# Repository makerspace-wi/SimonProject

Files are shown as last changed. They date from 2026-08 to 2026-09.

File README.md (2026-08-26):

# Simon Project

ESP32-basierte Steuerung fuer Fallblattanzeigen (MAN/Krone/Vossloh) mit:
- WiFi Access Point
- Weboberflaeche/HTTP-API
- Serieller Ausgabe im Krone-Protokoll
- I2C-Transfer von Byte-Werten an 3 Slave-Adressen (ADTrans)

## Projektziel

Dieses Projekt stellt mit einem ESP32 einen lokalen Access Point bereit. Ueber HTTP-Endpoints koennen Anzeigeinhalte gesetzt oder geloescht werden. Die Ausgabe an die Fallblattmodule erfolgt seriell im Format:

- Startbyte: `0x88`
- Adresse: `adress`
- Wert: `flip`
- Endbyte: `0x81`

## Verwendete Plattform

- MCU/Board: ESP32 (`wemos_d1_uno32`)
- Framework: Arduino
- Build-System: PlatformIO
- Webserver: `ESP32WebServer`
- mDNS: `ESPmDNS`
- I2C: `Wire`

Konfiguration: [platformio.ini](platformio.ini)

## Build und Upload

### Build

```bash
~/.platformio/penv/bin/platformio run
```

### Upload (Beispiel)

```bash
~/.platformio/penv/bin/platformio run -t upload
```

## Netzwerkverhalten

Beim Start erzeugt der ESP32 einen Access Point:
- SSID: `fallblatt.local`
- Passwort: `Fallblattanzeige`

Zusatz: mDNS wird mit Hostname `fallblatt` initialisiert.

## HTTP-Endpoints

Implementierung in [src/main.cpp](src/main.cpp).

### 1) Startseite

- `GET /`
- Liefert die HTML-Oberflaeche aus `MAIN_page` (Datei [src/web.h](src/web.h)).

### 2) Anzeige loeschen

- `GET /clear`
- Loescht/neutralisiert alle angesteuerten Fallblattpositionen.

### 3) Anzeige setzen

- `GET /flip`
- Erwartete Query-Parameter:
  - `b` = Betreiber
  - `g` = Gattung
  - `n` = Zugnummer
  - `s` = Abfahrtsstunde
  - `m` = Abfahrtsminute
  - `i1` = Info 1
  - `i2` = Info 2
  - `d` = Zwischenziel
  - `z` = Ziel

Beispiel:

```text
/flip?b=1&g=2&n=42&s=12&m=34&i1=5&i2=6&d=7&z=8
```

Hinweis:
- Der Endpoint `/flip` steuert zusaetzlich 3 I2C-Module (ADTrans) ueber `I2C_ADDR_1..3`.
- Je nach Laenge der Zugnummer werden Ziffern auf UART-Fallblattmodule und I2C-Module verteilt.

### 4) Zweites Modul (direkt im Programm gesteuert)

Die zweite serielle Schnittstelle (19200 Baud, BREAK-Protokoll) wird ohne eigenen HTTP-Endpoint direkt im Programmablauf gesteuert.

Aktuell erfolgt die Ansteuerung am Ende von `/flip` mit:

- Zieladresse aus `MODULE2_DIRECT_ADDR`
- Position aus dem bereits berechneten Feld `ziel`

Damit geht die Kommunikation fuer das zweite Modul nicht separat ueber den Webserver.

## I2C-Konfiguration

Standardwerte in [platformio.ini](platformio.ini):

- `I2C_ADDR_1=0x38`
- `I2C_ADDR_2=0x39`
- `I2C_ADDR_3=0x3A`

Optionale Pinbelegung (auskommentiert):
- `I2C_SDA_PIN`
- `I2C_SCL_PIN`

Wenn beide Pins gesetzt sind, wird `Wire.begin(SDA, SCL)` verwendet.
Andernfalls nutzt das Projekt `Wire.begin()` mit Board-Default.

## Genutzte IO-Pins

Aktueller Stand gemaess [platformio.ini](platformio.ini) und [src/main.cpp](src/main.cpp):

- Debug-UART (`Serial`): ueber USB-Seriell (Monitor 115200 Baud).
- Signal-UART (`Serial2`, 4800 Baud, 8E2):
  - TX: GPIO17 (`UART_SIGNAL_TX_PIN`)
  - RX: GPIO16 (`UART_SIGNAL_RX_PIN`)
- Modul-2-UART (`Serial1`, 19200 Baud, 8N1, BREAK-faehig):
  - TX: GPIO26 (`UART_MODULE2_TX_PIN`)
  - RX: GPIO27 (`UART_MODULE2_RX_PIN`)
  - Optional RS485 Driver-Enable: `UART_MODULE2_RS485_DE_PIN` (Standard `-1` = aus)
- I2C (`Wire`):
  - Aktuell keine festen Pins im Build-Flag gesetzt.
  - Es werden daher die Board-Defaults verwendet (`Wire.begin()`).
  - Optional konfigurierbar ueber `I2C_SDA_PIN` und `I2C_SCL_PIN` in [platformio.ini](platformio.ini).

Hinweis:
- Auf vielen ESP32-Boards liegt USB-Debug intern auf UART0 (typisch TX0=GPIO1, RX0=GPIO3).
- Fuer die Fallblattansteuerung wird ausschliesslich `Serial2` genutzt.
- Die ADTrans-I2C-Module werden mit `sendByte(...)` angesteuert (kein separater HTTP-I2C-Endpoint).

## Fallblatt-Adressen (seriell)

Die adressierten Module sind in [src/main.cpp](src/main.cpp) festgelegt, u. a.:
- Logo: `0x05`
- Gattung: `0x04`
- Zeichen 1/2: `0x03`, `0x02`
- Stunde/Minute: `0x01`, `0x00`
- Info 1/2: `0x07`, `0x06`
- Zwischenziel/Ziel: `0x08`, `0x09`

## Troubleshooting

### Build-Task in VS Code schlaegt fehl, Terminal-Build funktioniert

Symptom:
- VS-Code-Task meldet Fehler, manueller Build ist erfolgreich.

Pruefung/Fix:
- Sicherstellen, dass [/.vscode/tasks.json](.vscode/tasks.json) den PlatformIO-Pfad aus dem Python-Environment nutzt.
- Build direkt testen:

```bash
~/.platformio/penv/bin/platformio run
```

### Include-Fehler / IntelliSense findet Header nicht

Symptom:
- Meldung wie "Aktualisieren Sie Ihren includePath".

Pruefung/Fix:
- Einmal erfolgreichen Build ausfuehren, damit PlatformIO die Projektmetadaten aktualisiert.
- VS Code neu laden, falls die Meldung bestehen bleibt.
- In [platformio.ini](platformio.ini) das richtige Environment pruefen (`ESP32_WROOM`).

### Upload funktioniert nicht

Symptom:
- `run -t upload` bricht mit Port- oder Verbindungsfehler ab.

Pruefung/Fix:
- USB-Kabel/Port wechseln.
- Board-Typ in [platformio.ini](platformio.ini) pruefen (`wemos_d1_uno32`).
- Upload separat testen:

```bash
~/.platformio/penv/bin/platformio run -t upload
```

### I2C-Geraet reagiert nicht

Symptom:
- Ziffern auf den ADTrans-Modulen fehlen oder bleiben auf Leerwert.

Pruefung/Fix:
- I2C-Adressen in [platformio.ini](platformio.ini) mit den Slave-Adressen abgleichen (`I2C_ADDR_1..3`).
- Falls eigene Pins noetig sind, `I2C_SDA_PIN` und `I2C_SCL_PIN` in [platformio.ini](platformio.ini) aktivieren.
- GND zwischen ESP32 und I2C-Slaves gemeinsam verbinden.

### mDNS/Hostname nicht erreichbar

Symptom:
- `fallblatt.local` wird nicht aufgeloest.

Pruefung/Fix:
- Direkt per IP aufrufen statt Hostname.
- Sicherstellen, dass das Endgeraet im Access-Point des ESP32 eingebucht ist.
- AP-Daten pruefen: SSID `fallblatt.local`, Passwort `Fallblattanzeige`.

## Hinweise

- Das Projekt ist fuer die aktuelle ESP32-PlatformIO-Umgebung ausgelegt.
- Bei Problemen zuerst Build lokal pruefen und die Werte in [platformio.ini](platformio.ini) kontrollieren.

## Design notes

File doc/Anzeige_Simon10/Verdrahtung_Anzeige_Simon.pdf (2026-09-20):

Tabelle1

Anzeige Benennung Farbe
1
| GND | sw | 1
2
3
24V | or 4
5
6
7 | D5 | gn | 6
8 | D4 | or | 5
9 | D3 | ge | 4
10 | D2 | ws | 3
11 | D1 | rt | 2
12 | D0 | sw | 1
13 | REL | rt | 2
14 | ~24V | bl

### 15 bl

I2C
1 | GND | sw | 1
2 | 5V | rt | 2
3 | SDA | ge | 3
4 | SLC | ws | 4

RS485
1 | 5V | rt
2 | GND | sw

### 3 Data+ 4 Data-5 DI

6 | DE | }

### 7 RE 8 RO

Netzteil
1 ~230V L
2 ~230V N
1.1 | ~18V | bl
1.2 | ~18V | bl
2.1 | 27V | vio
2.2 | GND | sw
3.1 | 24V | or
3.2 | GND | sw

PCB
J1

PCB
J2

PCB
J3

PCB
RS485

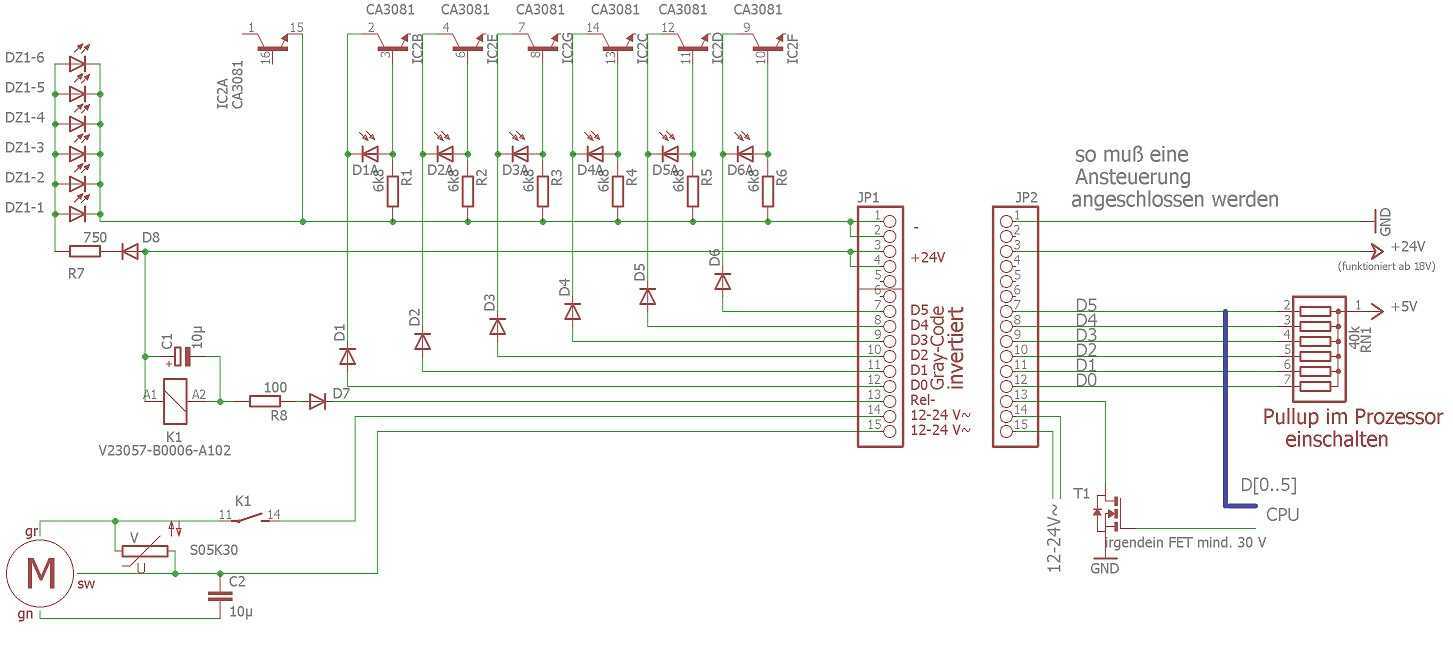
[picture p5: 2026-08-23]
doc/Anzeige_Simon10/ADTrans.jpeg

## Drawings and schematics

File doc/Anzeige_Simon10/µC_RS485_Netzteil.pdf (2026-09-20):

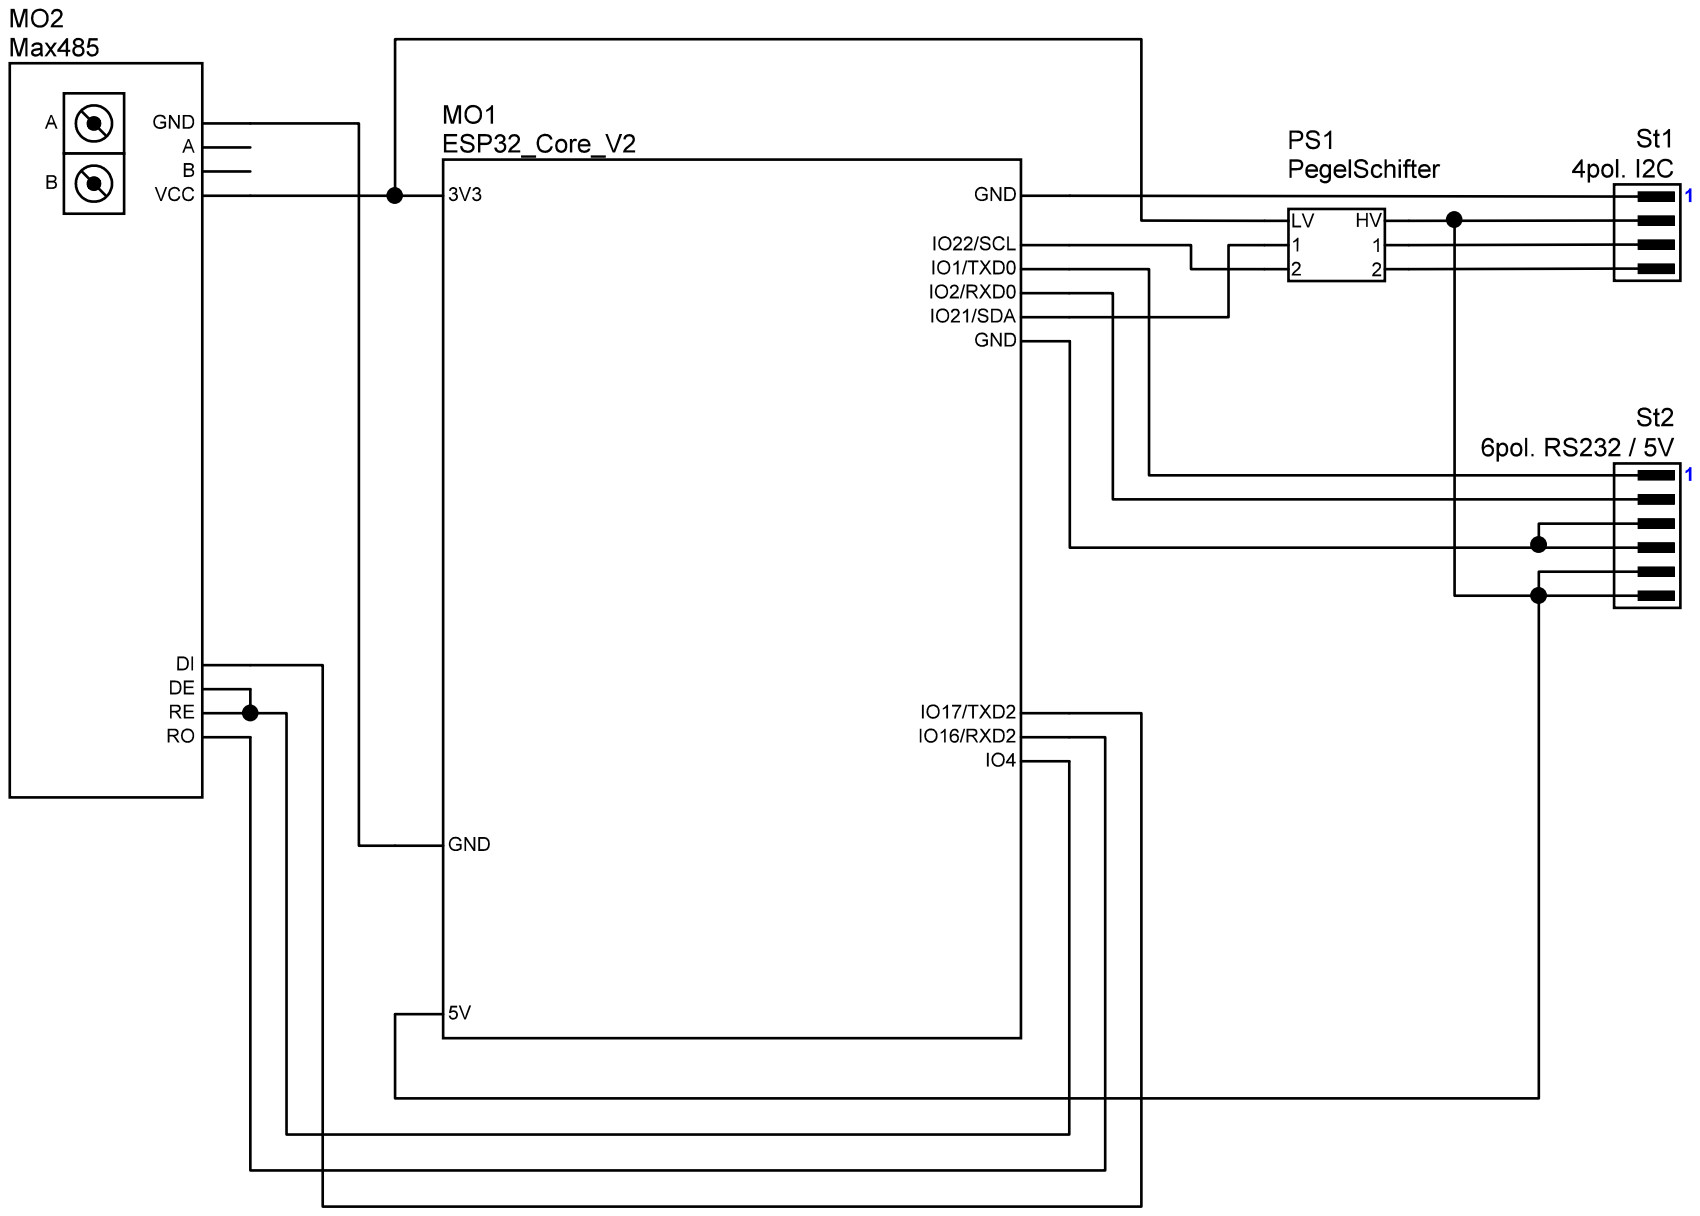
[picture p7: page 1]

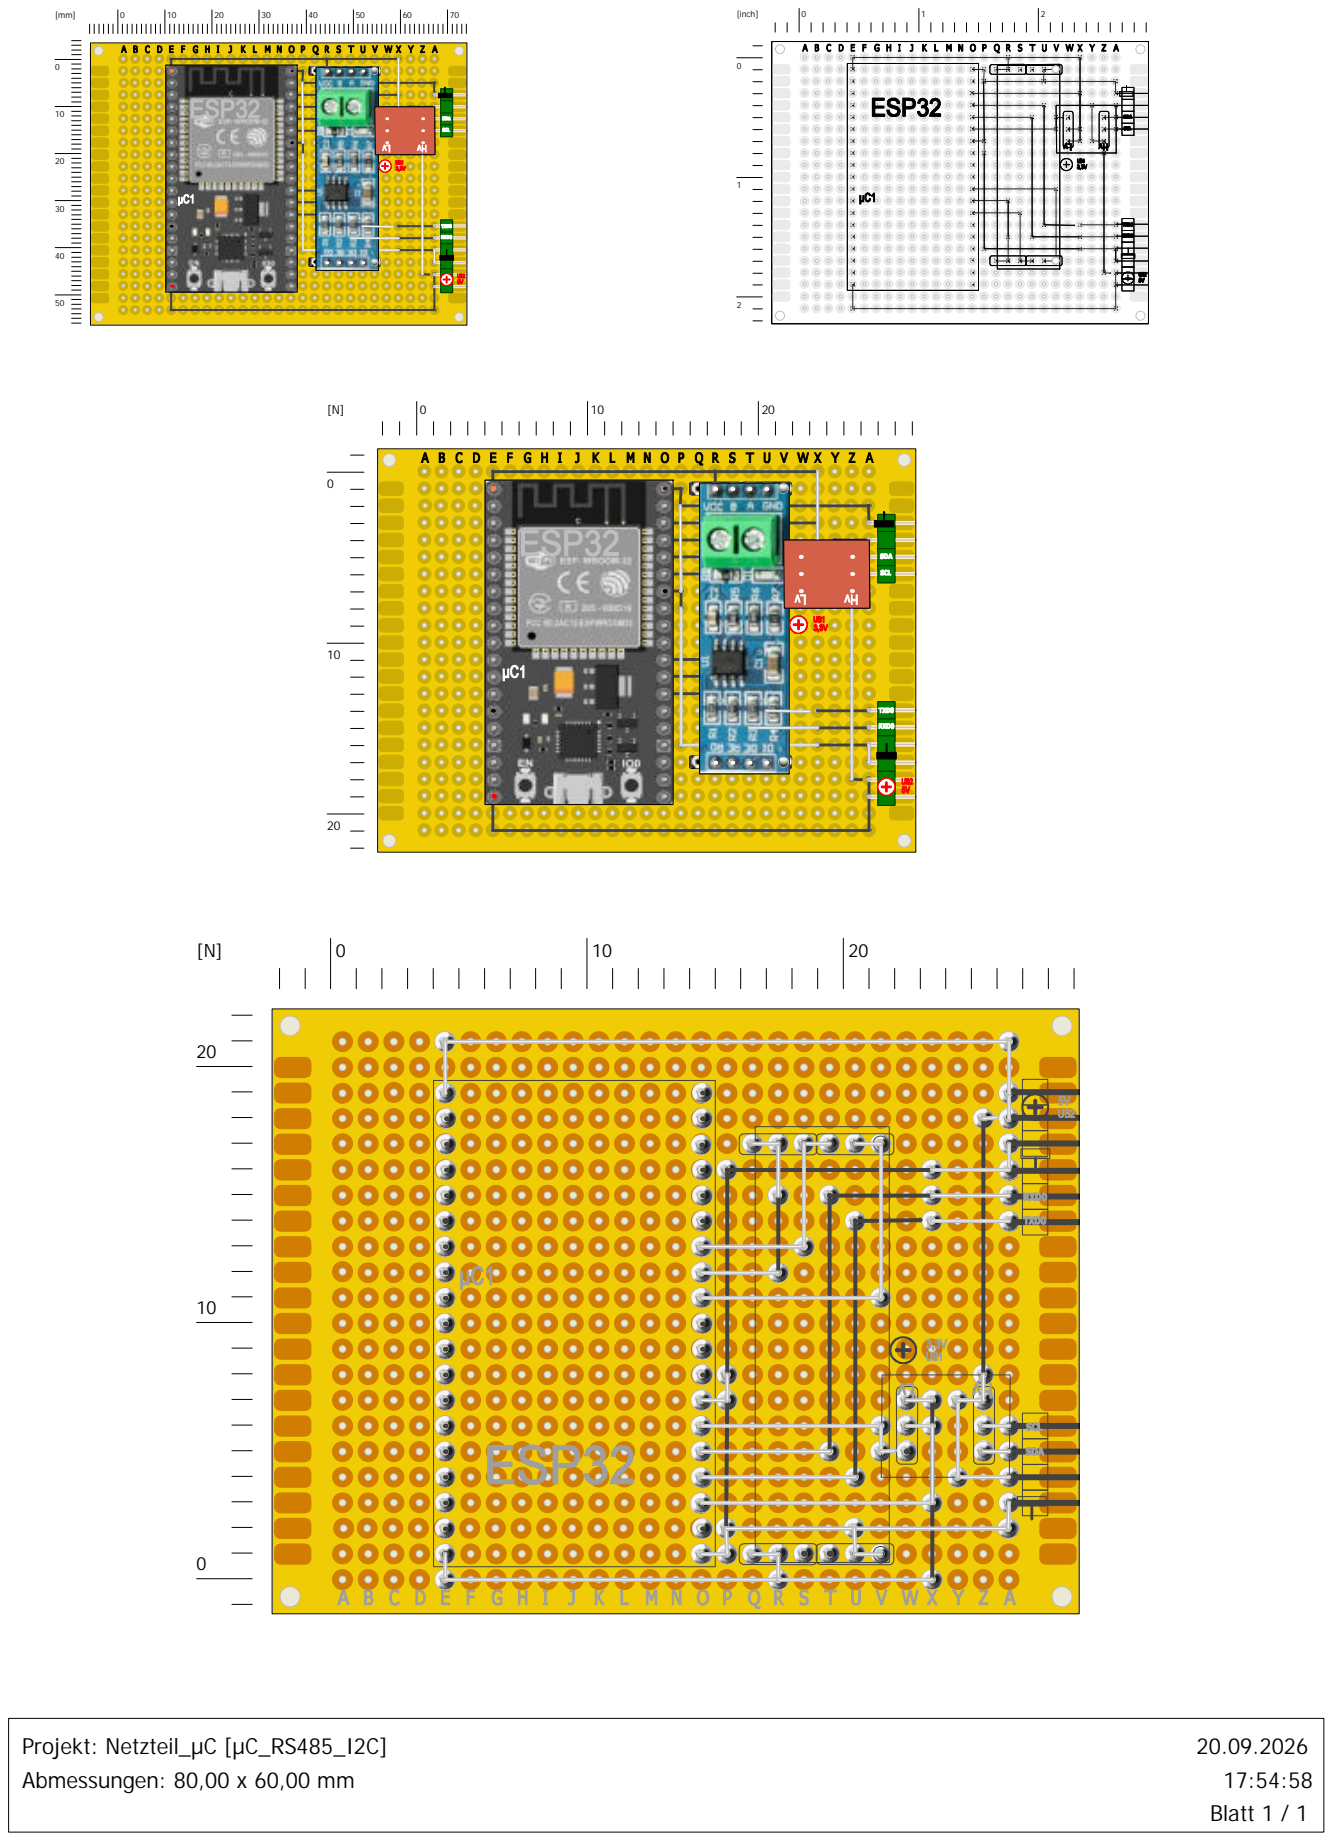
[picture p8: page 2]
[inch]; Projekt: Netzteil_µC [µC_RS485_I2C] Abmessungen: 80,00 x 60,00 mm; 20.09.2026 17:54:58 Blatt 1 / 1

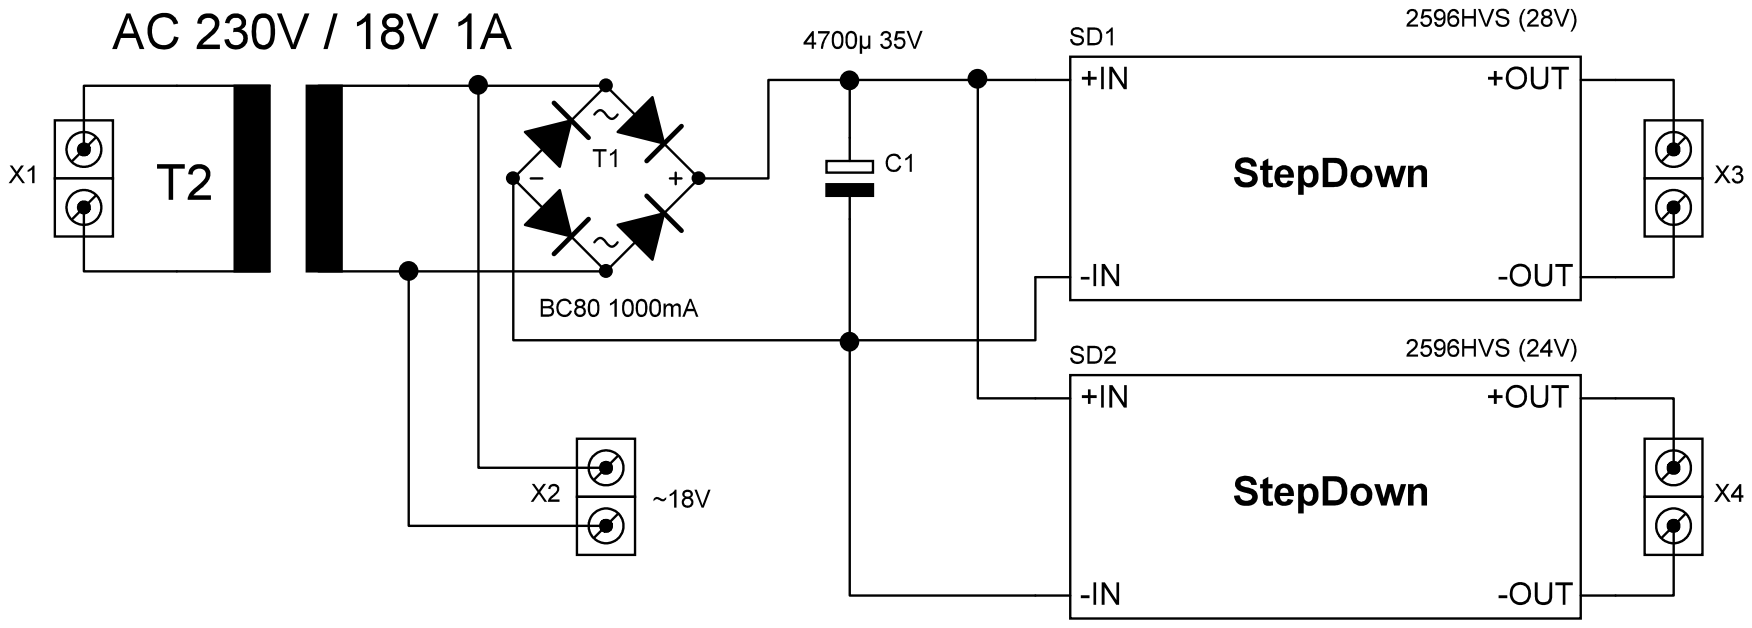
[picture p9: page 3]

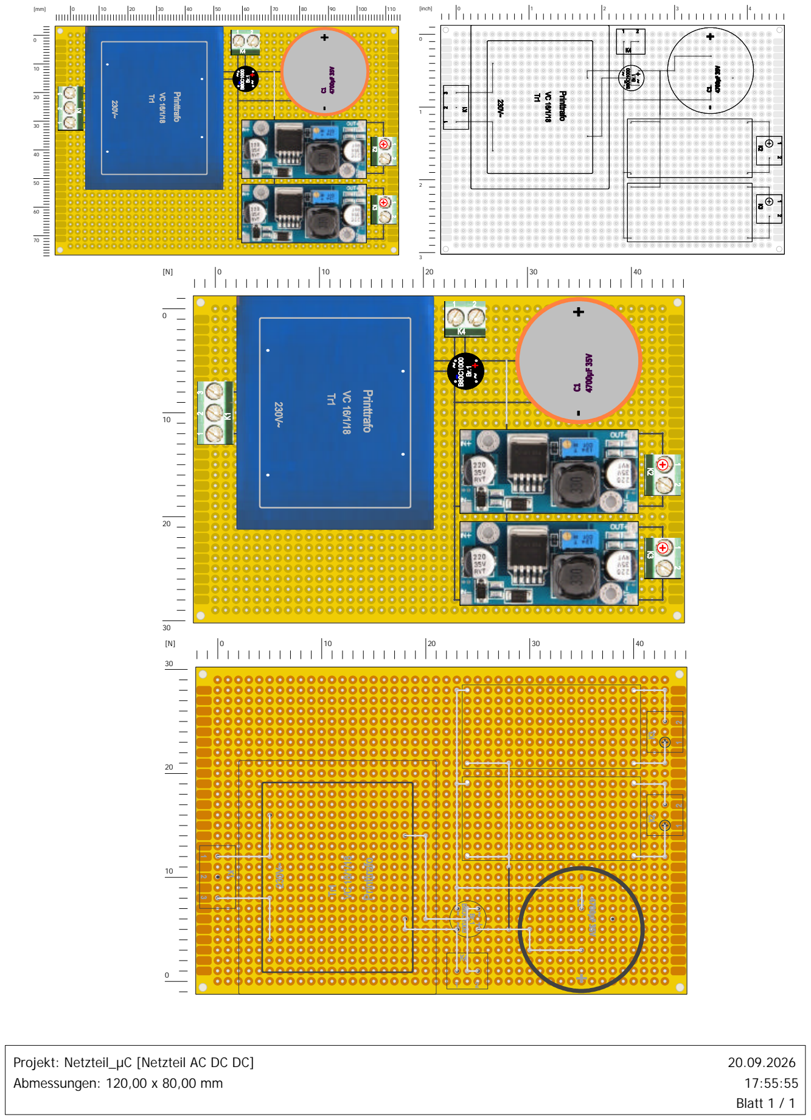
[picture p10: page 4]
[inch]; 20.09.2026 17:55:55 Blatt 1 / 1

Projekt: Netzteil_µC [Netzteil AC DC DC]
Abmessungen: 120,00 x 80,00 mm

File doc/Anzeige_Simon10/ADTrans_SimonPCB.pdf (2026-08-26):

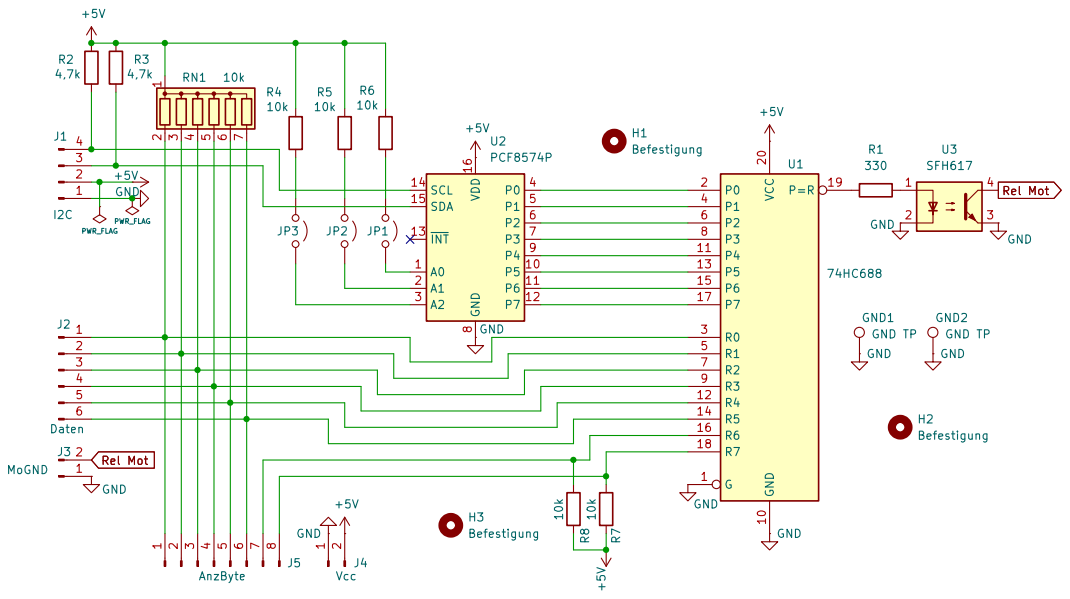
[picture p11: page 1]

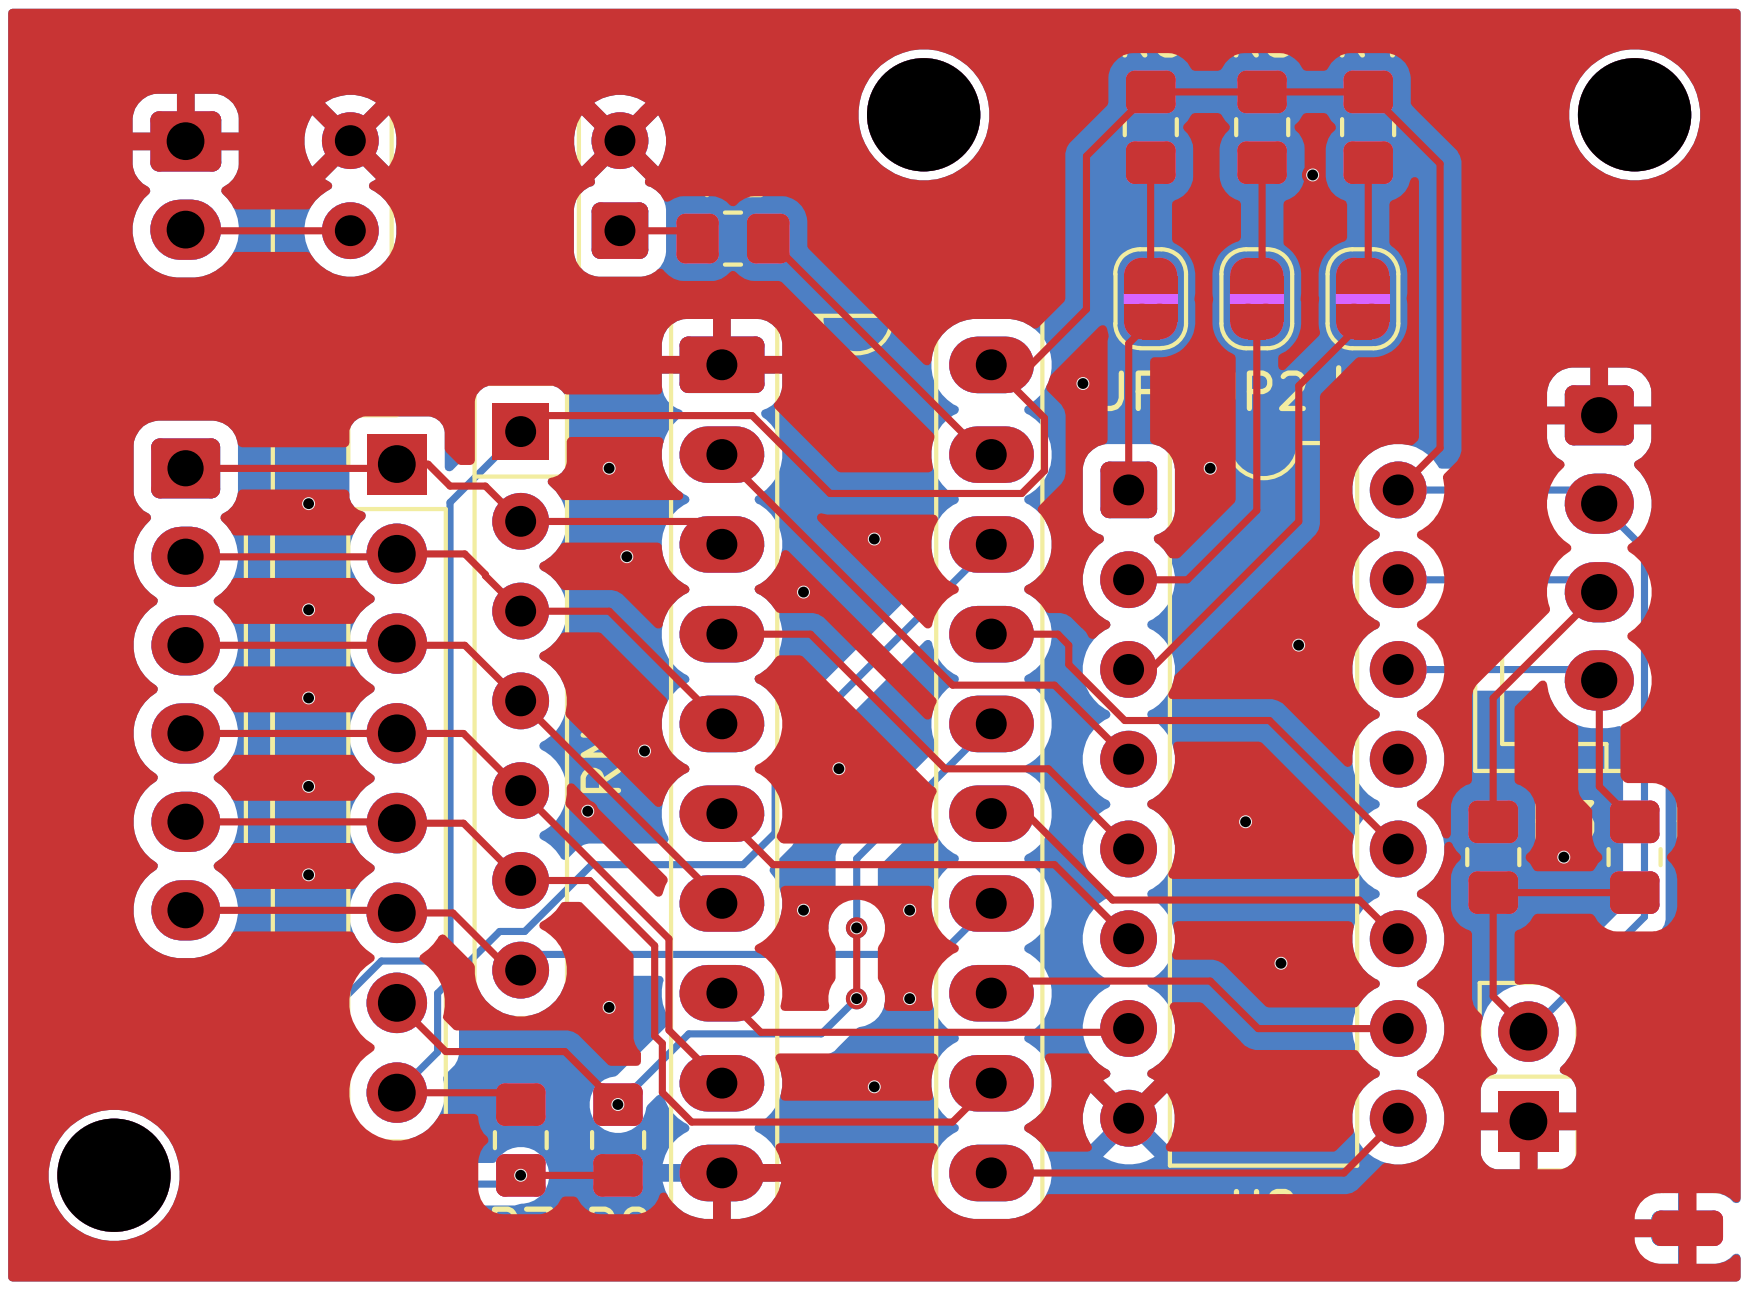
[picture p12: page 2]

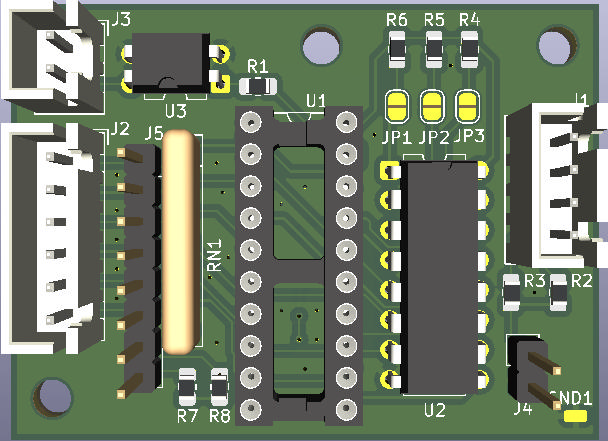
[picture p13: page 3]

1/1

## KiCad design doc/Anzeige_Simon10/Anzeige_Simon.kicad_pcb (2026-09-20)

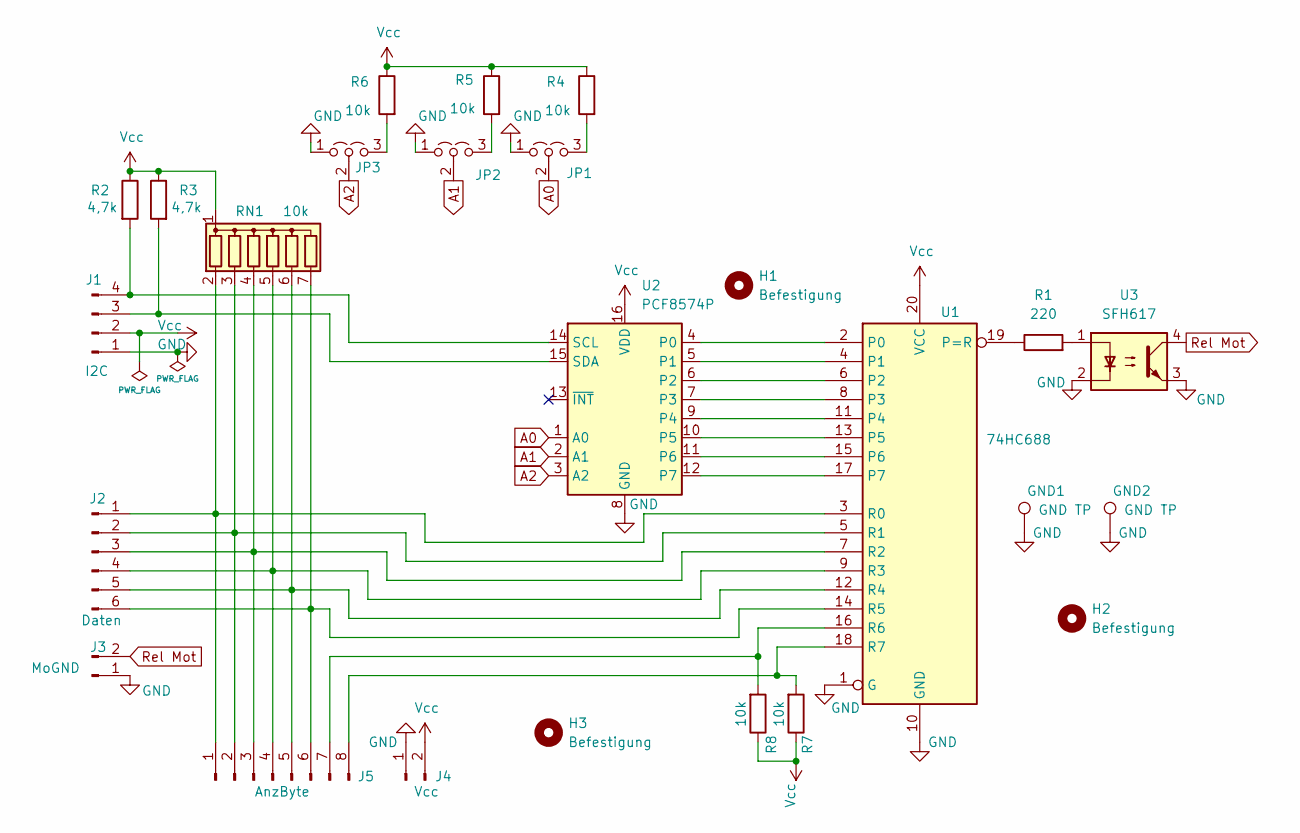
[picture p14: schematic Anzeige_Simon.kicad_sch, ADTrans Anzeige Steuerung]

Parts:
GND1, GND2: GND TP; SolderWirePad_1x01_SMD_1x2mm
H1, H2, H3: Befestigung; MountingHole_3.2mm_M3_ISO14580
J1: I2C; JST_XH_B4B-XH-A_1x04_P2.50mm_Vertical
J2: Daten; JST_XH_B6B-XH-A_1x06_P2.50mm_Vertical
J3: MoGND; JST_XH_B2B-XH-A_1x02_P2.50mm_Vertical
J4: Vcc; PinHeader_1x02_P2.54mm_Vertical
J5: AnzByte; PinHeader_1x08_P2.54mm_Vertical
JP1, JP2, JP3: Jumper_3_Open; SolderJumper-3_P1.3mm_Open_RoundedPad1.0x1.5mm
R1: 220; R_0805_2012Metric_Pad1.20x1.40mm_HandSolder
R2, R3: 4,7k; R_0805_2012Metric_Pad1.20x1.40mm_HandSolder
R4, R5, R6, R7, R8: 10k; R_0805_2012Metric_Pad1.20x1.40mm_HandSolder
RN1: 10k; R_Array_SIP7
U1: 74HC688; DIP-20_W7.62mm_Socket_LongPads
U2: PCF8574P; DIP-16_W7.62mm
U3: SFH617; DIP-4_W7.62mm

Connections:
A0: JP1.2 (C), U2.1 (A0)
A1: JP2.2 (C), U2.2 (A1)
A2: JP3.2 (C), U2.3 (A2)
GND: GND1.1 (1_1), GND2.1 (1_1), J1.1, J3.1, J4.1, JP1.1 (A), JP2.1 (A), JP3.1 (A), U1.1 (G), U1.10 (GND), U2.8 (GND), U3.2, U3.3
unnamed: J1.3, R3.2, U2.15 (SDA)
unnamed: J1.4, R2.2, U2.14 (SCL)
unnamed: J2.1, J5.1, RN1.2 (R1), U1.3 (R0)
unnamed: J2.2, J5.2, RN1.3 (R2), U1.5 (R1)
unnamed: J2.3, J5.3, RN1.4 (R3), U1.7 (R2)
unnamed: J2.4, J5.4, RN1.5 (R4), U1.9 (R3)
unnamed: J2.5, J5.5, RN1.6 (R5), U1.12 (R4)
unnamed: J2.6, J5.6, RN1.7 (R6), U1.14 (R5)
unnamed: J5.7, R8.2, U1.16 (R6)
unnamed: J5.8, R7.2, U1.18 (R7)
unnamed: JP1.3 (B), R4.2
unnamed: JP2.3 (B), R5.2
unnamed: JP3.3 (B), R6.2
unnamed: R1.2, U3.1
unnamed: U1.2 (P0), U2.4 (P0)
unnamed: U1.4 (P1), U2.5 (P1)
unnamed: U1.6 (P2), U2.6 (P2)
unnamed: U1.8 (P3), U2.7 (P3)
unnamed: U1.11 (P4), U2.9 (P4)
unnamed: U1.13 (P5), U2.10 (P5)
unnamed: U1.15 (P6), U2.11 (P6)
unnamed: U1.17 (P7), U2.12 (P7)
unnamed: R1.1, U1.19 (P=R)
Rel Mot: J3.2, U3.4
Vcc: J1.2, J4.2, R2.1, R3.1, R4.1, R5.1, R6.1, R7.1, R8.1, RN1.1 (common), U1.20 (VCC), U2.16 (VDD)

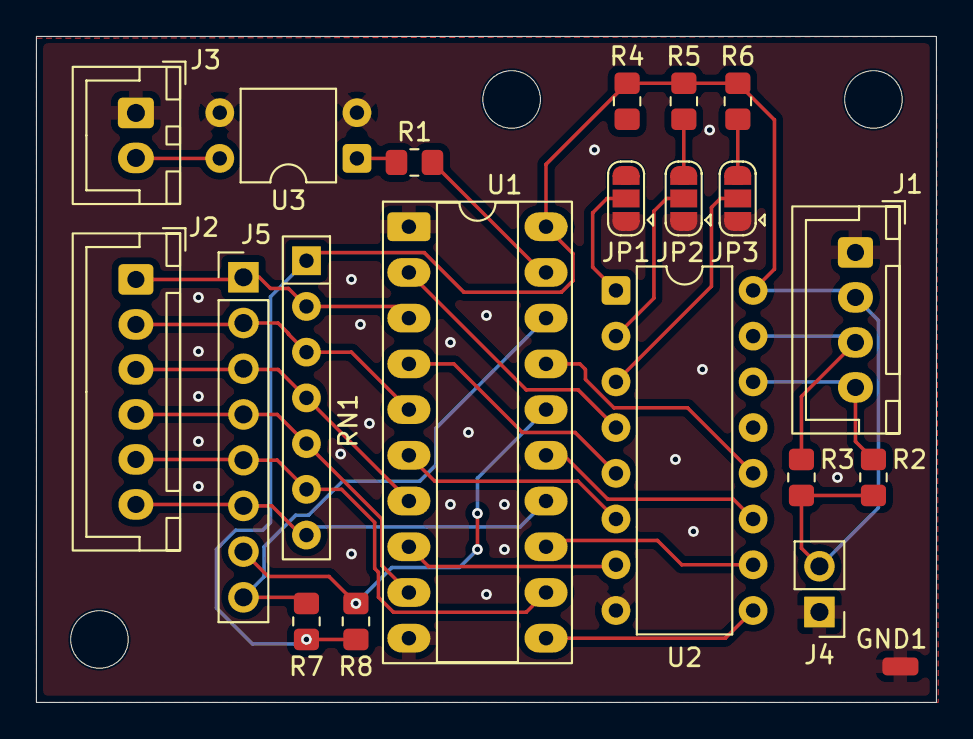
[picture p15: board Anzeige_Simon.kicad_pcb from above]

Board: 2 copper layers, 50.0 x 37.0 mm, 25 parts (1 on the bottom side), 29 nets.

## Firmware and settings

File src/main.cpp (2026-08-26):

#include <Arduino.h>
#include <Wire.h>
// Alex Kohl 2024 Krone Fallblattansteuerung mit ESP32 Email an mich: alex@alex14.de
// ESP32 als Wifi-AP zur Ansteuerung von MAN/Krone/Vossloh Fallblattanzeigen
// Module sind ueber eine serielle Verbindung angebunden
// Aufbau Message: [88] [Adresse] [Blatt] [81]
//  ZUM PROGRAMMIEREN: ESP32 UMBEDINGT von Adapter AUSSTECKEN!

// Einstellungen zum Programmieren:
// 1. PlatformIO-Umgebung: ESP32_WROOM
// 2. Board: wemos_d1_uno32
// 3. Framework: arduino
// >>>> Wenn unten orange Fehlermeldungen kommen, stimmt etwas nicht.
//      Meistens hilft Google oder mich einfach fragen.

// Sonderzeichen zu "Ersatzzeichen": https://www-user.tu-chemnitz.de/~lfe/selfhtml61/tcad.htm

// https://github.com/espressif/arduino-esp32/tree/master/libraries/WebServer
#include <ESP32WebServer.h>
const char *WiFiName = "fallblatt.local";
const char *WiFiPass = "Fallblattanzeige";
// https://github.com/espressif/arduino-esp32/tree/master/libraries/ESPmDNS
#include <ESPmDNS.h>

// web.h: ausgelagertes Webdokument, enthaelt das gesamte HTML
#include "web.h"

int address = 0;
int verschubzahl = 0;
ESP32WebServer server(80);

int laststatus = 3;

void returnConfigPage();
void clear();
void flip();
void setflip(byte adress, byte flip);
void sendByte(byte i2cAddress, byte zahl);
byte bin2grayi(byte n);

void module2SendCommand(uint8_t command, uint8_t address, const uint8_t *payload, size_t payloadLen);
void module2SetPosition(uint8_t address, uint8_t position);
void updateModule2Direct();

#ifndef UART_DEBUG_BAUD
#define UART_DEBUG_BAUD 115200
#endif

#ifndef UART_SIGNAL_BAUD
#define UART_SIGNAL_BAUD 4800
#endif

#ifndef UART_SIGNAL_RX_PIN
#define UART_SIGNAL_RX_PIN 16
#endif

#ifndef UART_SIGNAL_TX_PIN
#define UART_SIGNAL_TX_PIN 17
#endif

#ifndef UART_MODULE2_BAUD
#define UART_MODULE2_BAUD 19200
#endif

#ifndef UART_MODULE2_RX_PIN
#define UART_MODULE2_RX_PIN 27
#endif

#ifndef UART_MODULE2_TX_PIN
#define UART_MODULE2_TX_PIN 26
#endif

#ifndef UART_MODULE2_BREAK_BITS
#define UART_MODULE2_BREAK_BITS 24
#endif

#ifndef UART_MODULE2_RS485_DE_PIN
#define UART_MODULE2_RS485_DE_PIN -1
#endif

#ifndef MODULE2_DIRECT_ENABLED
#define MODULE2_DIRECT_ENABLED 1
#endif

#ifndef MODULE2_DIRECT_ADDR
#define MODULE2_DIRECT_ADDR 0x0A
#endif

#ifndef I2C_ADDR_1
#define I2C_ADDR_1 0x10
#endif

#ifndef I2C_ADDR_2
#define I2C_ADDR_2 0x11
#endif

#ifndef I2C_ADDR_3
#define I2C_ADDR_3 0x12
#endif

#ifndef I2C_SDA_PIN
#define I2C_SDA_PIN -1
#endif

#ifndef I2C_SCL_PIN
#define I2C_SCL_PIN -1
#endif

// I2C-Zieladressen fuer Integer-Transfers
const uint8_t i2cAddress1 = static_cast<uint8_t>(I2C_ADDR_1);
const uint8_t i2cAddress2 = static_cast<uint8_t>(I2C_ADDR_2);
const uint8_t i2cAddress3 = static_cast<uint8_t>(I2C_ADDR_3);

// Adressen der Fallblattmodule
byte logoadress = 0x05;
byte gattungadress = 0x04;
byte char1 = 0x03;
byte char2 = 0x02;

byte stdadress = 0x01;
byte minadress = 0x00;

byte infoadress = 0x07;
byte infoadress2 = 0x06;
byte zieladress = 0x09;

byte zwischenzieladress = 0x08;

// Uebergebene Variablen
int betreiber, gattung, abmin, abstd, zugnummer, info1, info2, zwischenziel, ziel;
String s_betreiber, s_gattung, s_abmin, s_abstd, s_zugnummer, s_info1, s_info2, s_zwischenziel, s_ziel;

void setup()
{
  Serial.begin(UART_DEBUG_BAUD);
  Serial2.begin(UART_SIGNAL_BAUD, SERIAL_8E2, UART_SIGNAL_RX_PIN, UART_SIGNAL_TX_PIN);
  Serial1.begin(UART_MODULE2_BAUD, SERIAL_8N1, UART_MODULE2_RX_PIN, UART_MODULE2_TX_PIN);
  Serial.println("Debug-UART aktiv (Serial)");
  Serial.println("Signal-UART aktiv (Serial2)");
  Serial.println("Modul-2-UART aktiv (Serial1, BREAK + FF Cx Protokoll)");

#if UART_MODULE2_RS485_DE_PIN >= 0
  pinMode(UART_MODULE2_RS485_DE_PIN, OUTPUT);
  digitalWrite(UART_MODULE2_RS485_DE_PIN, LOW);
#endif

#if (I2C_SDA_PIN >= 0) && (I2C_SCL_PIN >= 0)
  Wire.begin(I2C_SDA_PIN, I2C_SCL_PIN);
#else
  Wire.begin();
#endif
  delay(100);
  WiFi.mode(WIFI_AP);
  WiFi.softAP(WiFiName, WiFiPass);
  WiFi.softAPIP();
  if (!MDNS.begin("fallblatt"))
  {
    Serial.println("Error setting up MDNS responder!");
    while (1)
    {
      delay(1000);
    }
  }

  // Serial.println(WiFi.localIP());

  server.on("/", returnConfigPage);

  server.on("/clear", clear);
  server.on("/flip", flip);
  server.begin();
}

void loop()
{
  server.handleClient();
#if defined(ARDUINO_ARCH_ESP8266)
  MDNS.update();
#endif
}

// Bereitet einkommende Daten auf und leitet entsprechendes Blaettern ein
void flip()
{
  s_betreiber = server.arg("b");
  int str_len1 = s_betreiber.length() + 1;
  char wertigkeit1[str_len1];
  s_betreiber.toCharArray(wertigkeit1, str_len1);
  betreiber = atoi(wertigkeit1);

  s_gattung = server.arg("g");
  int str_len2 = s_gattung.length() + 1;
  char wertigkeit2[str_len2];
  s_gattung.toCharArray(wertigkeit2, str_len2);
  gattung = atoi(wertigkeit2);

  s_zugnummer = server.arg("n");
  int str_len3 = s_zugnummer.length() + 1;
  char wertigkeit3[str_len3];
  s_zugnummer.toCharArray(wertigkeit3, str_len3);
  zugnummer = atoi(wertigkeit3);

  s_abstd = server.arg("s");
  int str_len4 = s_abstd.length() + 1;
  char wertigkeit4[str_len4];
  s_abstd.toCharArray(wertigkeit4, str_len4);
  abstd = atoi(wertigkeit4);

  s_abmin = server.arg("m");
  int str_len5 = s_abmin.length() + 1;
  char wertigkeit5[str_len5];
  s_abmin.toCharArray(wertigkeit5, str_len5);
  abmin = atoi(wertigkeit5);

  s_info1 = server.arg("i1");
  int str_len6 = s_info1.length() + 1;
  char wertigkeit6[str_len6];
  s_info1.toCharArray(wertigkeit6, str_len6);
  info1 = atoi(wertigkeit6);

  s_info2 = server.arg("i2");
  int str_len7 = s_info1.length() + 1;
  char wertigkeit7[str_len7];
  s_info2.toCharArray(wertigkeit7, str_len7);
  info2 = atoi(wertigkeit7);

  s_zwischenziel = server.arg("d");
  int str_len8 = s_zwischenziel.length() + 1;
  char wertigkeit8[str_len8];
  s_zwischenziel.toCharArray(wertigkeit8, str_len8);
  zwischenziel = atoi(wertigkeit8);

  s_ziel = server.arg("z");
  int str_len9 = s_ziel.length() + 1;
  char wertigkeit9[str_len9];
  s_ziel.toCharArray(wertigkeit9, str_len9);
  ziel = atoi(wertigkeit9);

  // DEBUG-Ausgabe
Serial.println("Betreiber: " + String(betreiber) + " Gattung: " + String(gattung) + " Zugnummer: " + String(zugnummer) + " Abfahrt: " + String(abstd) + ":" + String(abmin) + " Info1: " + String(info1) + " Info2: " + String(info2) + " Zwischenziel: " + String(zwischenziel) + " Ziel: " + String(ziel));

  // Zugnummer berechnen
  int len = String(abs(zugnummer)).length();
  byte einer = 0;
  byte zehner = 0;
  byte hunderter = 0;
  byte tausender = 0;
  byte ztausender = 0;

  if (zugnummer == 0)
  {
    // Clear Zugnummeranzeige
    setflip(char2, 35);
    setflip(char1, 35);
    sendByte(i2cAddress1, 0xFF);
    sendByte(i2cAddress2, 0xFF);
    sendByte(i2cAddress3, 0xFF);
  }
  else
  {
    einer = zugnummer % 10;
    zehner = (zugnummer / 10) % 10;
    hunderter = (zugnummer / 100) % 10;
    tausender = (zugnummer / 1000) % 10;
    ztausender = (zugnummer / 10000) % 10;

    switch (len)
    {
    case 0:
      // sending commands to clear all 5 displays
      setflip(char2, 35);
      setflip(char1, 35);
      sendByte(i2cAddress1, 0xFF);
      sendByte(i2cAddress2, 0xFF);
      sendByte(i2cAddress3, 0xFF);
      // set the 3 ADTrans Modules to NONE
      break;
    case 1:
      // set char1 and clear char2 - char5
      setflip(char2, map(einer, 0, 9, 48, 57));
      setflip(char1, 35);
      sendByte(i2cAddress1, 0xFF);
      sendByte(i2cAddress2, 0xFF);
      sendByte(i2cAddress3, 0xFF);
      break;
    case 2:
      // set char1 & char2 and clear char3 - char5
      setflip(char2, map(zehner, 0, 9, 48, 57));
      setflip(char1, map(einer, 0, 9, 48, 57));
      sendByte(i2cAddress1, 0xFF);
      sendByte(i2cAddress2, 0xFF);
      sendByte(i2cAddress3, 0xFF);
      break;
    case 3:
      // set char1 & char2 & char3 and clear char4 - char5
      setflip(char2, map(hunderter, 0, 9, 48, 57));
      setflip(char1, map(zehner, 0, 9, 48, 57));
      sendByte(i2cAddress1, 0xFF);
      sendByte(i2cAddress2, 0xFF);
      sendByte(i2cAddress3, bin2grayi(einer));
      break;
    case 4:
      // set char1, char2, char3, char4 and clear char5
      setflip(char2, map(tausender, 0, 9, 48, 57));
      setflip(char1, map(hunderter, 0, 9, 48, 57));
      sendByte(i2cAddress3, bin2grayi(zehner));
      sendByte(i2cAddress2, bin2grayi(einer));
      sendByte(i2cAddress1, 0xFF);
      break;
    case 5:
      // set char1, char2, char3, char4, char5
      setflip(char2, map(ztausender, 0, 9, 48, 57));
      setflip(char1, map(tausender, 0, 9, 48, 57));
      sendByte(i2cAddress3, bin2grayi(hunderter));
      sendByte(i2cAddress2, bin2grayi(zehner));
      sendByte(i2cAddress1, bin2grayi(einer));
      break;
    default:
      break;
    }
  }
  
  
  // Abfahrtszeit
  if (abstd != 0 && abmin != 0)
  {
    setflip(stdadress, map(abstd, 0, 23, 34, 57));
    setflip(minadress, map(abmin, 0, 59, 34, 93));
  }

  setflip(logoadress, betreiber);
  setflip(gattungadress, gattung);
  setflip(infoadress, info1);
  setflip(infoadress2, info2);
  setflip(zieladress, ziel);
  setflip(zwischenzieladress, zwischenziel);

  updateModule2Direct();
}

// convert number to Gray code for the ADTrans modules, because they are not binary coded
byte bin2grayi(byte n)
{
  n += 1;
  return (~(n ^ (n >> 1)) & ((1 << 8) - 1));
}

// Sorgt fuer ein Leerblaettern der Module
// 0x82 klappt nicht bei allen Modulen, daher wurde einfach alles einzeln angesteuert
void clear()
{
  if (laststatus != 0)
  {
    // Serial.write(0x82);
    delay(100);
    setflip(stdadress, 32);
    setflip(minadress, 32);
    setflip(char2, 32);
    setflip(char1, 32);
    setflip(logoadress, 130);
    setflip(gattungadress, 32);
    setflip(infoadress, 32);
    setflip(infoadress2, 32);
    setflip(zieladress, 32);
    setflip(zwischenzieladress, 103);

    sendByte(i2cAddress1, 0xFF);
    sendByte(i2cAddress2, 0xFF);
    sendByte(i2cAddress3, 0xFF);

    laststatus = 0;
  }
}

// Gibt die Daten aus nach dem Krone-Protokoll
void setflip(byte adress, byte flip)
{

  for (int i = 0; i <= 0; i++)
  {
    Serial2.write(0x88);   // 88 Beginn Übertrag
    Serial2.write(adress); //  Adresse
    Serial2.write(flip);   //  Char
    Serial2.write(0x81);   // 81 Ende Übertrag
    delay(20);
  }

  laststatus = 1;
} // End setflip()

void module2SendCommand(uint8_t command, uint8_t address, const uint8_t *payload, size_t payloadLen)
{
  uint8_t frame[8];
  size_t frameLen = 0;

  frame[frameLen++] = 0xFF;
  frame[frameLen++] = command;
  frame[frameLen++] = address;

  for (size_t i = 0; i < payloadLen && frameLen < sizeof(frame); ++i)
  {
    frame[frameLen++] = payload[i];
  }

#if UART_MODULE2_RS485_DE_PIN >= 0
  digitalWrite(UART_MODULE2_RS485_DE_PIN, HIGH);
  delayMicroseconds(80);
#endif

  // Protokoll fordert BREAK vor dem Frame.
  const uint32_t breakUs = (static_cast<uint32_t>(UART_MODULE2_BREAK_BITS) * 1000000UL + UART_MODULE2_BAUD - 1) / UART_MODULE2_BAUD;
  Serial1.flush();
  Serial1.end();
  pinMode(UART_MODULE2_TX_PIN, OUTPUT);
  digitalWrite(UART_MODULE2_TX_PIN, LOW);
  delayMicroseconds(breakUs);
  digitalWrite(UART_MODULE2_TX_PIN, HIGH);
  delayMicroseconds(40);

  Serial1.begin(UART_MODULE2_BAUD, SERIAL_8N1, UART_MODULE2_RX_PIN, UART_MODULE2_TX_PIN);

  while (Serial1.available() > 0)
  {
    Serial1.read();
  }

  Serial1.write(frame, frameLen);
  Serial1.flush();

#if UART_MODULE2_RS485_DE_PIN >= 0
  digitalWrite(UART_MODULE2_RS485_DE_PIN, LOW);
#endif
}

void module2SetPosition(uint8_t address, uint8_t position)
{
  uint8_t payload[1] = {position};
  module2SendCommand(0xC0, address, payload, 1);
}

void updateModule2Direct()
{
  #if MODULE2_DIRECT_ENABLED
  module2SetPosition(static_cast<uint8_t>(MODULE2_DIRECT_ADDR), static_cast<uint8_t>(ziel & 0xFF));
  #endif
}


void sendByte(byte i2cAddress, byte zahl)
{
  Wire.beginTransmission(i2cAddress);
  Wire.write(zahl);
  Wire.endTransmission();
}

// Fuer WiFi-AP
void returnConfigPage()
{
  server.send(200, "text/html", MAIN_page);
}

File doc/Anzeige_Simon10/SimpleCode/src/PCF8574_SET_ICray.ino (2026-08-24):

#include <Arduino.h>
#include <Wire.h>
 
const uint8_t PCF_ADDR = 0x38;
int val = 0;
int value = 255; // initial value for all ports high (inputs/high-Z)
int maxValue = 63; // max value for 6 bit output
String inStr = ""; // a string to hold incoming data

// FUNCTIONS ------------------------------------
int getNum(String strNum) // Check if realy numbers
{
  strNum.trim();
  for (byte i = 0; i < strNum.length(); i++)
  {
    if (!isDigit(strNum[i])) 
    {
      Serial.println("Error: no number from 0 - " + String(maxValue));
      return value;
    }
  }
  return strNum.toInt();
}

int bin2gray(byte n)
{
  return 0b11111111 & ~(n ^ (n >> 1));
}
// End Funktions --------------------------------
 
// Funktions Serial Input (Event) ---------------
void evalSerialData()
{
  if (inStr.length() <4)
  { 
    val = getNum(inStr);
    if (val > maxValue) 
    {
      Serial.println("Error: > " + String(maxValue));
    }
    else  
    {
      value = bin2gray(val);
    }
    Serial.println("Value: " + String(val) + " -> InvGray: " + String(value));
    Serial.print(F("Value:"));
  }
  else
  {
    Serial.println(F("Error: max 2 digits"));
    Serial.print(F("Value:"));
  }
}
// End Funktions Serial Input -------------------

void setup()
{
  Wire.begin(); 
  Serial.begin(115200);
  inStr.reserve(10);    // reserve for instr serial input

  // Initialize all ports high (inputs/high-Z)
  Wire.beginTransmission(PCF_ADDR);
  Wire.write(value);
  Wire.endTransmission();
 
  Serial.print(F("Value:"));
}
 
// PROGRAM LOOP AREA ----------------------------
void loop()
{
  if (Serial.available() > 0)
  {
    char inChar = (char)Serial.read();
    if (inChar == '\x0d')
    {
      evalSerialData();
      inStr = "";
    }
    else if (inChar != '\x0a')
    {
      inStr += inChar;
    }
  }
  // Set test value AA
  Wire.beginTransmission(PCF_ADDR);
  Wire.write(value);  // value set the output
  Wire.endTransmission();
  
  delay(50);

}

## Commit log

2026-08-25 Delete doc/Anzeige_Simon10/gerber_to_order directory
    new testpoints
    [Anzeige_Simon.GBL, Anzeige_Simon.GBO, Anzeige_Simon.GBP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]
2026-08-25 update files
    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
    [Anzeige_Simon.kicad_pcb, Anzeige_Simon.kicad_sch]
2026-08-26 update file
    add holes
2026-08-26 update files
    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
    [Anzeige_Simon.kicad_pcb, Anzeige_Simon.kicad_sch]
2026-08-28 add file for power supply
    power supply for 18V~ 28V= 24V=
2026-09-20 Update files
    [Anzeige_Simon.kicad_pcb, Anzeige_Simon.kicad_sch]
